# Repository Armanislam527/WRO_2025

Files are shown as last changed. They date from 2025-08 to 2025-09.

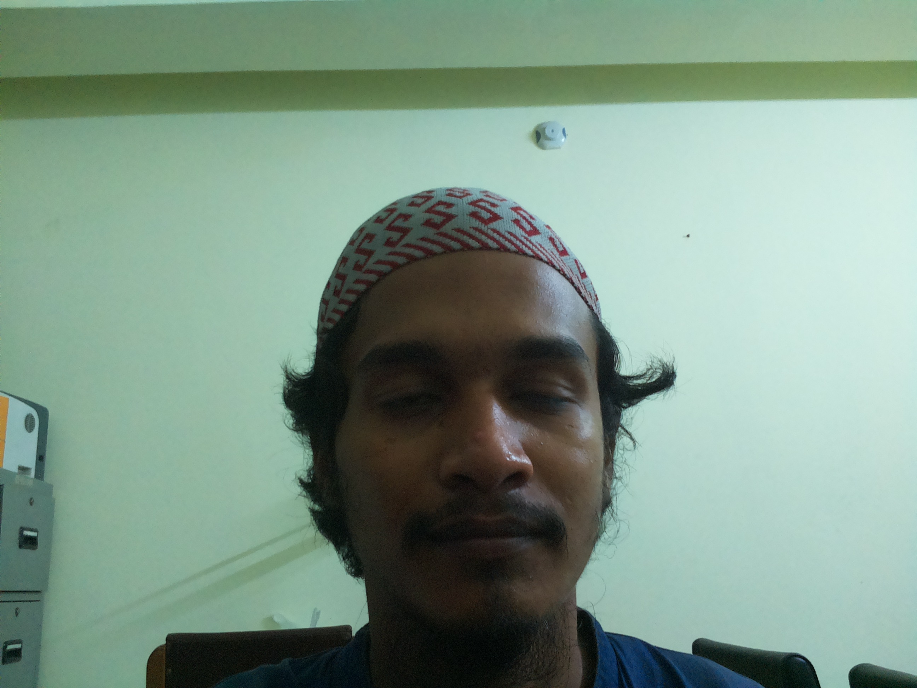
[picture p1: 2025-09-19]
test.jpg

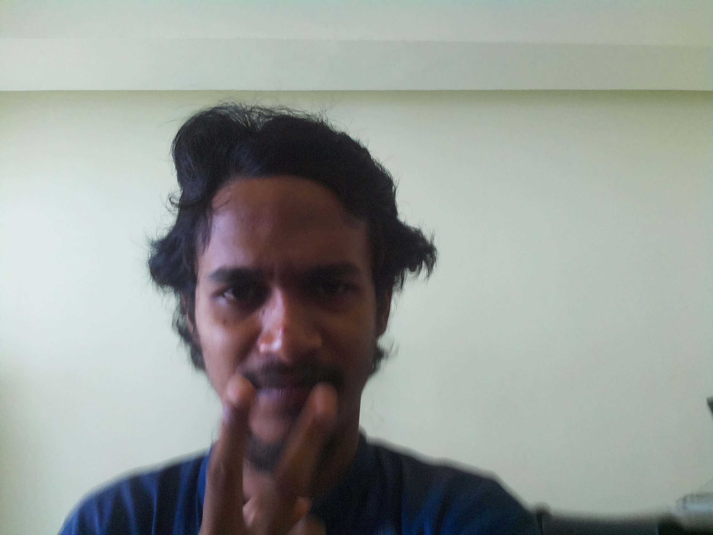
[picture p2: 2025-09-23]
Pictures/test.jpg

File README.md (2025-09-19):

# WRO 2025 Future Engineers: Self-Driving Car - Team void_error

<!-- ![void_error Team Logo or Action Shot](Pictures/team_in_action.jpg) *Consider adding a team logo or a dynamic action shot here* -->

**Team Members:**

-   **Arman** (Leader) - Lead Programmer, Chassis Designer [Arman](http://github.com/Armanislam527/WRO_2025/tree/main/Pictures/arman.jpeg)
-   **Sajid Hasan Rohit** -Member [Rohit](http://github.com/Armanislam527/WRO_2025/tree/main/Pictures/rohit.jpeg)
-   **Habibul Bashar Labib** - Member [Labib](http://github.com/Armanislam527/WRO_2025/tree/main/Pictures/labib.jpg)
-   **Basim Al Zabir Shammo** (Coach) - Guide and inspires the team to build the project [Shammo](http://github.com/Armanislam527/WRO_2025/tree/main/Pictures/shammo.jpg)

**Affiliation:** [Pabna University of Science and technology,Pabna,Bangladesh]

**Repository Status:**  

## 1. Project Philosophy & Introduction

Welcome to the engineering journey of Team void_error for the WRO 2025 Future Engineers category!

This repository serves as the living archive of our autonomous vehicle project, meticulously crafted for the Self-Driving Car challenges. Our endeavor transcends merely building a robot; it embodies our commitment to the WRO Guiding Principles, emphasizing learning, teamwork, creativity, and ethical competition.

We believe engineering is a symphony of iterative design, rigorous problem-solving, and seamless collaboration. This project reflects that belief. From the initial spark of an idea, through countless hours of design, coding, testing, debugging, and refining, every commit in this repository tells a story of our growth, our challenges overcome, and our relentless pursuit of excellence on the WRO track.

Our vehicle is not just a collection of electromechanical parts; it is the physical manifestation of algorithms, strategic thinking, and the fusion of open-source hardware and software. It is designed to perceive its environment, make intelligent decisions, and navigate the randomized complexities of the Open and Obstacle Challenges with precision and autonomy.

## 2. Vehicle Description & Key Features

### 2.1. Core Design Ethos

Our design philosophy centers on **robustness, modularity, and efficiency**. We aimed to create a platform that is not only competitive but also adaptable and easy to maintain. Key tenets include:

-   **Distributed Intelligence:** Leveraging both the computational strengths of the Raspberry Pi Zero 2W (for complex vision tasks) and the real-time control capabilities of the Arduino Nano (for sensor fusion and actuator control) to achieve optimal performance.
-   **Sensor Fusion:** Integrating data from multiple sensors (IMU, IR, Ultrasonics, Camera) to build a comprehensive understanding of the vehicle's state and its surroundings, leading to more informed and reliable decisions.
-   **Transparent Communication:** Implementing a clear, high-speed serial protocol between the Pi and Nano to ensure seamless coordination and data exchange.
-   **Iterative Development:** Our approach involved continuous testing, analysis of results, identification of bottlenecks, and targeted refinements. This process is documented through our commit history.

### 2.2. Mechanical Architecture

-   **Chassis:** A custom-designed, 3D-printed frame tailored for a **4-Wheel Drive (4WD) configuration with front-wheel steering**. This design provides superior traction and stability, crucial for the dynamic nature of the WRO tracks. The STL and GCODE files reside in the `RC Chassis/` directory, representing numerous iterations for optimal weight distribution and component integration.
-   **Propulsion:** **Rear-wheel drive** is implemented using high-torque DC motors, delivering the necessary power for acceleration and overcoming minor inclines or resistances on the track.
-   **Steering:** Precise directional control is achieved through a **front-wheel steering mechanism** actuated by a dedicated servo motor, enabling agile turns and accurate path following.
-   **Compliance:** The vehicle strictly adheres to WRO dimensional regulations (maximum 300mm length x 200mm width x 300mm height).
-   **Materials:** The primary structure utilizes **PLA filament** for 3D-printed components, balancing strength, printability, and weight. Standard RC components are integrated where appropriate for specific functionalities like motors and servos.

### 2.3. Electronic & Control Systems

The vehicle's nervous system is a carefully orchestrated interplay of controllers, sensors, and actuators.

-   **Dual-Controller Architecture:**
    -   **Primary Controller (Brain): Arduino Nano (`nano_brain/nano_brain.ino`)**
        -   **Responsibilities:** Acts as the real-time control hub. Manages low-level sensor interfacing (MPU6050 IMU, IR sensors, Ultrasonic sensors), executes core navigation algorithms (line following, turn detection using IMU integration, lap counting), directly controls actuators (motors via L298N H-Bridge, steering servo), and handles high-speed serial communication with the Pi.
        -   **Key Strengths:** Deterministic real-time performance, efficient handling of time-critical tasks, robust sensor data acquisition and preprocessing.
    -   **Secondary Controller (Vision/Strategy): Raspberry Pi Zero 2W (`coding_part/pi_main.py`)**
        -   **Responsibilities:** Serves as the high-level intelligence unit. Processes visual data from the onboard camera using computer vision techniques, implements complex decision-making logic (path planning, obstacle/sign interpretation), manages the overall mission state machine, and communicates strategic commands (desired speed, steering angle) to the Nano.
        -   **Key Strengths:** Powerful computational capabilities for image processing, ability to run complex algorithms, flexible software environment for rapid prototyping and strategy adjustments.
-   **Sensor Suite:**
    -   **MPU6050 IMU:** Critical for inertial navigation, specifically employed for highly accurate **gyroscopic turn detection** (by integrating the Z-axis rate) and reliable **lap counting**.
    -   **IR Reflectance Sensors (x4):** Strategically positioned to detect the contrast between the track surface and its boundaries, forming the backbone of the **line-following algorithm**.
    -   **Ultrasonic Distance Sensors (x2):** Provide range measurements to the front and rear, useful for obstacle detection (in Obstacle Challenge) and potentially for parking maneuvers.
    -   **USB Camera:** The primary sensor for environmental perception, feeding visual data to the Pi for advanced processing.
-   **Actuation:**
    -   **DC Motors (x2 - Rear Drive):** Controlled precisely via the L298N H-Bridge driver, enabling forward, backward, and variable speed movement.
    -   **Servo Motor (x1 - Front Steering):** Provides accurate angular control for steering, translating high-level directional commands into physical wheel movement.
-   **Communication Backbone:** A **high-speed serial link (configured at 500,000 baud)** ensures low-latency, reliable data transfer between the Pi and Nano, facilitating real-time coordination.
-   **Power Management:** A dedicated strategy involves a **lithium-ion battery pack**. Power is distributed via a **buck converter** to provide a stable 5V supply for the logic circuits (Nano, Pi, sensors) and direct, regulated power to the motor drivers for optimal performance.

### 2.4. Vehicle view

-   ## The vehicle view is below:
    -**<br>Front View [Front Vied](http://github.com/Armanislam527/WRO_2025/tree/main/Pictures/front.jpeg)**<br> -**Left View [Left View](http://github.com/Armanislam527/WRO_2025/tree/main/Pictures/lef.jpeg)**<br> -**Right View [Right View](http://github.com/Armanislam527/WRO_2025/tree/main/Pictures/right.jpeg)**<br> -**Rear View [Rear View](http://github.com/Armanislam527/WRO_2025/tree/main/Pictures/rear_view.jpeg)**<br> -**Top View [Top View](http://github.com/Armanislam527/WRO_2025/tree/main/Pictures/up.jpeg)**<br> -**Bottom View [Bottom View](http://github.com/Armanislam527/WRO_2025/tree/main/Pictures/down.jpeg)**<br>

## 3. Software Architecture & Modules

The software for our WRO 2025 vehicle is a distributed system split between the **Arduino Nano** and the **Raspberry Pi Zero 2W**, leveraging the strengths of each platform.

-   **Arduino Nano (`nano_brain/`):** This microcontroller acts as the real-time control core. Its responsibilities include:

    -   **Low-Latency I/O:** Reading sensors (IR, Ultrasonics, MPU6050) and controlling actuators (motors via L298N, servo) with precise timing.
    -   **Sensor Fusion & Preprocessing:** Performing initial processing on raw sensor data (e.g., reading MPU6050 registers, basic IR/US filtering).
    -   **Reliable Communication:** Managing the high-speed serial link with the Pi, packaging sensor data, and interpreting commands.
    -   **Fallback Logic:** Potentially executing basic reactive behaviors (like simple line following or emergency stops) if communication with the Pi is lost.
    -   **Code Language:** C++ (Arduino Sketch `.ino`).

-   **Raspberry Pi Zero 2W (`coding_part/`):** This single-board computer (SBC) handles high-level computation and strategy:
    -   **Computer Vision (CV):** Capturing images from the USB camera and processing them using libraries like OpenCV (`cv2`) to extract critical information such as lane position, traffic sign detection, and potentially parking lot identification.
    -   **Complex Decision Making:** Implementing the core navigation strategy, including line-following control algorithms (e.g., PID), interpreting sensor data (especially fused IMU data for turns/laps), managing the mission state machine (Start, Lap Driving, Sign Obeying, Parking Search, Parking Maneuver), and determining high-level commands (target speed, steering angle).
    -   **Path Planning:** Calculating the desired trajectory based on the perceived environment and challenge rules.
    -   **Communication Coordination:** Sending calculated commands (motor speeds, servo angles) to the Nano via the serial link.
    -   **Code Language:** Python 3.x.

Communication between the two is achieved via a **high-speed, binary serial protocol**. The Nano periodically sends sensor data packets to the Pi, and the Pi sends back actuator command packets. This decouples high-level cognition from real-time control, enhancing overall system responsiveness and robustness.

### 3.1. Arduino Nano (`nano_brain/nano_brain.ino`)

This section details the core logic running on the Arduino Nano, the vehicle's real-time processing unit.

-   **Initialization (`void setup()`):**

    1.  **Pin Configuration:** Initializes digital and PWM pins for motors (`MOTOR_IN1`, `MOTOR_IN2`, `MOTOR_PWM`), servo (`SERVO_PIN`), and digital inputs for sensors (`IR_PINS`, `START_BUTTON_PIN`).
    2.  **Peripheral Setup:**
        -   **I2C Bus:** Initializes the I2C bus (`Wire.begin()`) for communication with the MPU6050 IMU.
        -   **MPU6050:** Attempts to initialize the MPU6050 sensor. It writes to configuration registers (Power Management, Gyro/Accel config) and verifies communication by reading the `WHO_AM_I` register. Sends a status message (`NANO_READY_MPU_OK` or `NANO_READY_MPU_FAIL`) via serial.
        -   **Servo Attachment:** Attaches the steering servo to its designated pin using the `Servo` library.
    3.  **Serial Communication:** Begins serial communication at the predefined high baud rate (`SERIAL_BAUD`, e.g., 500000) to establish the link with the Pi.
    4.  **Timer Initialization:** Records the initial timestamp (`last_sensor_send_time`, `last_button_check_time`) for managing periodic tasks.

-   **Main Control Loop (`void loop()`):**

    1.  **Periodic Tasks:**
        -   **Button Check:** Periodically polls the start button pin with software debouncing to detect the official start signal from the judge.
        -   **Sensor Reading:** Calls functions to read data from all connected sensors (IR array, Ultrasonic sensors, MPU6050). This involves reading digital pins, sending trigger pulses, measuring echo durations, and performing I2C transactions with the IMU.
        -   **Data Packaging:** Combines the acquired sensor data into a structured format (e.g., a `SensorData` struct) for efficient transmission.
    2.  **Communication Handling:**
        -   **Sensor Transmission:** At a fixed interval (`SENSOR_SEND_INTERVAL_MS`), serializes the packaged `SensorData` struct and sends it to the Pi using a defined binary packet structure (e.g., `0xAA` header, data bytes, `0x55` footer).
        -   **Command Reception:** Listens for incoming serial data from the Pi. Parses command packets (e.g., `CMD:<speed>,<angle>\n`, `ENABLE_PI_CONTROL\n`) and updates internal target variables (`target_motor_speed`, `target_servo_angle`) or state flags (`pi_control_override`).
    3.  **Actuator Control:**
        -   **Motor Control:** Updates the motor driver outputs (`digitalWrite` to IN pins, `analogWrite` to EN pin) based on the current `target_motor_speed`.
        -   **Servo Control:** Updates the servo position (`steering_servo.write()`) based on the current `target_servo_angle`.
    4.  **State Management:**
        -   Waits in a loop until the start button signal is received and processed.
        -   Responds to the `pi_control_override` flag. If true, it executes commands received from the Pi. If false (e.g., fallback mode), it might execute a basic local control routine.

-   **Key Supporting Functions:**
    -   `bool initialize_mpu6050()`: Handles the specific initialization sequence for the MPU6050.
    -   `void read_ir_sensors()`, `int16_t read_ultrasonic(...)`, `void read_mpu6050_data()`: Dedicated functions for reading individual sensor types.
    -   `void process_serial_command()`: Parses incoming serial data from the Pi.
    -   `void update_motors()`, `void update_servo()`: Wrapper functions to apply the calculated target values to the physical actuators.

### 3.2. Raspberry Pi Zero 2W (`coding_part/pi_main.py`)

This section outlines the high-level Python script running on the Raspberry Pi Zero 2W, responsible for vision, strategy, and commanding the Nano.

-   **Initialization (`def main()` and setup code):**

    1.  **Library Imports:** Imports necessary Python libraries (`serial`, `cv2`, `numpy`, `time`, `threading`, etc.).
    2.  **Configuration Loading:** Reads configuration parameters (e.g., serial port `SERIAL_PORT`, baud rate `BAUD_RATE`, camera resolution `FRAME_WIDTH` x `FRAME_HEIGHT`, HSV color ranges for line/sign detection, control gains like `STEERING_P_GAIN`).
    3.  **Serial Connection:** Establishes a serial connection to the Arduino Nano using `pyserial` with the matching port and high baud rate.
    4.  **Camera Setup:** Initializes the USB camera using `cv2.VideoCapture`, setting properties like resolution and potentially buffer size for optimal performance.
    5.  **State Variable Initialization:** Resets run-specific variables (e.g., `state = STATE_WAITING_FOR_START`, `lap_count = 0`, `turn_count = 0`, sensor data buffers).
    6.  **Threading (Optional but Recommended):** Starts a separate thread dedicated to continuously reading sensor data packets from the serial port. This prevents the main control loop from blocking on serial reads. This thread parses incoming packets and updates shared data variables (e.g., `imu_data_raw`, `ir_sensor_states`) in a thread-safe manner (e.g., using `threading.Lock`).

-   **Main Execution Loop (`while not stop_event.is_set():` within `main()`):**

    1.  **Start Signal Handling:** Checks for the "START" signal received from the Nano (either via a specific flag set by the serial reader thread or by parsing a startup message). Upon receiving it, transitions the internal state machine to `STATE_DRIVING_LAPS`.
    2.  **Sensor Data Access:** Retrieves the latest sensor data shared by the serial reader thread (e.g., IMU gyro Z for turn counting, IR states for line following adjustments).
    3.  **Camera Processing (`process_camera_frame()`):**
        -   **Image Capture:** Grabs a frame from the camera (`cap.read()`).
        -   **Preprocessing:** Applies necessary corrections (e.g., resizing, color space conversion like BGR to HSV).
        -   **Feature Detection:**
            -   **Lane Following:** Analyzes the frame (e.g., ROI near the bottom) using techniques like color thresholding (white/black) and edge detection to find the track boundaries. Calculates a lateral error (distance from vehicle centerline to track center).
            -   **Traffic Sign Detection:** Uses color filtering (red/green HSV ranges) and shape analysis (contour detection) to identify and locate traffic signs relative to the vehicle.
            -   **Parking Lot Detection (Obstacle Challenge):** Looks for specific visual markers (e.g., magenta boundaries) to identify the parking lot entrance.
        -   **Output:** Returns the calculated lane error, detected sign information (type, position), and parking lot information (if detected).
    4.  **State Machine Logic (`calculate_control_commands()`):**
        -   Based on the current `state` (e.g., `STATE_DRIVING_LAPS`, `STATE_OBEYING_SIGN`, `STATE_PARKING_SEARCH`, `STATE_PARKING_MANEUVER`), it:
            -   **Integrates Sensor Data:** Uses IMU gyro Z data to count turns and laps.
            -   **Applies Control Laws:** Implements algorithms (e.g., Proportional-Derivative (PD) control) based on the lane error from vision to calculate the desired steering angle. Adjusts base speed based on steering effort or state requirements.
            -   **Manages Missions:** Handles logic for obeying traffic signs (modifying path based on sign color/side) and executing the parking sequence (searching for lot, performing maneuvers).
            -   **State Transitions:** Automatically transitions between states (e.g., from `DRIVING_LAPS` to `PARKING_SEARCH` after 3 laps, from `OBEYING_SIGN` back to `DRIVING_LAPS`).
    5.  **Command Generation:** Based on the outputs of the state machine and control logic, calculates the final `motor_speed` (integer, -255 to 255) and `servo_angle` (integer, 0 to 180).
    6.  **Serial Communication (`send_command_to_nano()`):**
        -   Formats the calculated commands into the agreed-upon protocol packet (e.g., `CMD:<motor_speed>,<servo_angle>\n`).
        -   Sends the packet to the Nano via the serial port.
    7.  **Loop Timing:** Controls the loop rate (e.g., using `time.sleep()`) to ensure stable processing and communication without overwhelming the system.

-   **Key Supporting Functions:**
    -   `def process_camera_frame(frame)`: Encapsulates the computer vision pipeline.
    -   `def update_lap_count(gyro_z_rate)`: Handles the integration of IMU data for accurate lap and turn counting.
    -   `def calculate_control_commands(...)`: Contains the core decision-making and control algorithm logic.
    -   `def send_command_to_nano(command_str)`: Handles formatting and transmitting commands via serial.
    -   `def serial_reader_thread()`: (If used) The function run by the background thread for asynchronous serial data reception.

## 4. Building, Flashing, and Running the Vehicle

This section provides a step-by-step guide to reproduce the hardware assembly and software setup of our WRO 2025 vehicle. Following these instructions should allow another competent team to build and run a functionally equivalent vehicle based on our design and code.

### 4.1. Prerequisites

Before beginning the build, ensure you have the following components, tools, and software environments ready.

-   **Hardware Components:**
    -   **Electromechanical Parts:**
        -   1x Arduino Nano (ATmega328P)
        -   1x Raspberry Pi Zero 2W
        -   1x MicroSD Card (8GB or larger, Class 10 recommended) pre-flashed with Raspberry Pi OS Bullseye or Bookworm Lite
        -   1x L298N Dual H-Bridge Motor Driver Module
        -   2x DC Motors with Gearbox (e.g., 6V, 200:1 reduction ratio)
        -   1x Standard Servo Motor (e.g., SG90 or MG90S)
        -   4x Digital Infrared (IR) Reflectance Sensors (e.g., TCRT5000 or equivalent)
        -   2x Ultrasonic Distance Sensors (e.g., HC-SR04)
        -   1x MPU6050 6-Axis Gyro/Accelerometer Module
        -   1x Wide-Angle USB Camera Module (e.g., compatible with Pi Zero)
        -   1x 4WD RC Chassis Kit (or custom 3D printed frame - see `RC Chassis/`)
        -   4x Wheels (compatible with motors/axles)
        -   1x Steering Linkage (tie rods, steering knuckle - custom or from RC kit)
        -   Jumper Wires (Male-to-Male, Male-to-Female, Female-to-Female)
        -   1x Mini Breadboard
        -   1x 18650 Lithium-Ion Battery Pack (e.g., 4S, ~14.8V, 7800mAh) with holder
        -   1x 5V Buck Converter Module (e.g., MP1584 or LM2596)
        -   1x Push Button (Momentary, Normally Open)
        -   1x 10kΩ Resistor (for button pull-up)
        -   1x Power Switch
        -   Fasteners (screws, nuts, zip ties) for mounting components
    -   **Tools:**
        -   Phillips Head Screwdriver
        -   Soldering Iron and Solder (for secure electrical connections)
        -   Wire Strippers/Cutters
        -   Allen Keys (if required for 3D printed parts or RC kit)
        -   3D Printer (if using custom `RC Chassis/` models) or access to laser cutting/CNC (if applicable)
        -   Calipers (for precise measurements during assembly)
-   **Software Environment:**
    -   **On a Development Computer:**
        -   Arduino IDE (version 1.8.19 or later, or Arduino CLI) for flashing the Nano.
        -   Git client for cloning this repository.
        -   (Optional but Recommended) Visual Studio Code or similar IDE for editing Python code.
    -   **On the Raspberry Pi Zero 2W:**
        -   Raspberry Pi OS (Bullseye Lite or Bookworm Lite recommended for performance/resource usage).
        -   Python 3.x (usually pre-installed).
        -   Required Python Libraries:
            -   `opencv-python` (for camera and computer vision)
            -   `numpy` (numerical computations)
            -   `pyserial` (for serial communication with Nano)
            -   `smbus2` or `smbus` (for I2C communication with MPU6050, if needed by alternative libraries)
            -   `RPi.GPIO` (usually pre-installed, for GPIO control if needed directly on Pi)
        -   Internet access on the Pi (via USB Ethernet gadget, WiFi, or Ethernet) for initial software installation.

### 4.2. Hardware Assembly

Follow these steps to assemble the physical vehicle. Reference the 3D models in `RC Chassis/` and the pin diagrams in `pin_diagram/` for precise component placement and connections.

1.  **Prepare the Chassis:**
    -   If using the custom 3D printed design, print the required parts from the STL files in `RC Chassis/` using appropriate settings (e.g., 0.2mm layer height, 20% infill). Ensure print quality is good, especially for parts requiring precise fit (motor mounts, servo mounts).
    -   If using an RC kit, follow the kit's instructions for the base frame assembly.
    -   Identify mounting points for the Arduino Nano, Raspberry Pi, L298N driver, battery pack, and sensors.
2.  **Mount Electronic Components:**
    -   **Arduino Nano & Breadboard:** Secure the Arduino Nano and mini breadboard to the chassis using standoffs or adhesive pads. Ensure it's firmly attached and vibration-resistant.
    -   **Raspberry Pi Zero 2W:** Mount the Pi in a safe, accessible location, ideally with a protective case. Ensure the USB camera can be mounted with an unobstructed view ahead.
    -   **L298N Driver:** Mount the L298N driver, ensuring adequate ventilation if it gets hot. Secure it firmly.
    -   **Sensors:**
        -   **IR Sensors (x4):** Mount the IR sensors beneath the front of the chassis. Angle them slightly inwards to detect the track edges. The front-left (FL) and front-right (FR) sensors should point towards the immediate track boundary. The right-45 (R45) and left-45 (L45) sensors should be angled ~45 degrees outwards to provide additional lateral awareness or assist with turn detection/sign reading. Ensure they are at a consistent, low height above the track surface.
        -   **Ultrasonic Sensors (x2):** Mount one US sensor on the front bumper and one on the rear bumper. Ensure the transducers are perpendicular to the front/rear surfaces for accurate distance measurement.
        -   **MPU6050 IMU:** Mount the IMU module in a central, stable location on the chassis, away from high-current cables (like those to the motors) to minimize electromagnetic interference. Orient it consistently (e.g., chip side up, specific axis forward) and note the orientation for potential calibration.
        -   **Servo Motor:** Mount the steering servo securely in the designated position (usually part of the 3D printed steering assembly or RC kit). Connect the steering linkage (tie rods) from the servo arm to the steering knuckle/axle.
    -   **Motors:** Attach the DC motors to the motor mounts on the chassis. Connect the wheels to the motor shafts/axles. Ensure the rear wheels are the drive wheels.
    -   **Camera:** Mount the USB camera at the front, elevated and tilted slightly downwards to capture the track ahead. The exact height and angle might require fine-tuning during calibration.
3.  **Complete Electrical Connections:**
    -   **Crucial:** Double-check _every_ connection against the wiring diagrams provided in `pin_diagram/data_connection.csv` and `pin_diagram/power_source.csv`. Incorrect wiring can damage components.
    -   **Power Distribution:**
        -   Connect the positive terminal of the 18650 battery pack to the `VCC` input of the L298N module.
        -   Connect the negative terminal of the battery pack to the `GND` input of the L298N and to the common ground rail of your main power distribution system (e.g., breadboard GND rail).
        -   Connect the `5V` output of the Buck Converter to the `+5V` power rail (e.g., breadboard `+` rail).
        -   Connect the `GND` output of the Buck Converter to the common ground rail (e.g., breadboard `-` rail).
        -   Power the Arduino Nano, Raspberry Pi, Sensors, and Servo Logic from the `+5V` and `GND` rails.
    -   **Nano to Components:**
        -   Connect Nano pins to IR sensor digital outputs, US sensor trigger/echo pins, servo signal pin, L298N control pins (ENA, IN1, IN2, IN3, IN4, ENB if using 2 motors), MPU6050 SDA/SCL pins, and the start button pin, according to `nano_brain/nano_brain.ino` and `pin_diagram/data_connection.csv`.
        -   Ensure correct I2C pull-up resistors are used or present on the MPU6050 module.
    -   **Pi to Components:**
        -   Connect the Pi's camera module to the dedicated CSI port.
        -   Connect the Pi's USB OTG port to the Arduino Nano's USB port (for power and serial communication). _Or_, if using separate power and UART serial:
            -   Connect Pi's UART TX (GPIO 14) to Nano's RX (D0) via a logic level shifter if needed (though often 3.3V->5V works for RX).
            -   Connect Pi's UART RX (GPIO 15) to Nano's TX (D1) via a logic level shifter (5V->3.3V is _required_ here).
            -   Connect Pi's GND to Nano's GND.
    -   **L298N to Motors:**
        -   Connect motor power (from battery pack `VCC` and `GND`) to the L298N motor supply terminals.
        -   Connect the two DC motor wires to the L298N output terminals (OUT1/OUT2 for Motor A, OUT3/OUT4 for Motor B).
        -   Connect the L298N logic control pins (ENA, IN1, IN2, IN3, IN4, ENB) to the corresponding Arduino Nano pins.
    -   **Start Button & Switch:**
        -   Wire the push button between the designated Nano input pin (e.g., A3) and GND. Use the internal pull-up resistor configured in the Nano code (`pinMode(START_BUTTON_PIN, INPUT_PULLUP);`) or add an external 10kΩ pull-up resistor between the pin and `+5V`.
        -   Wire the main power switch in series with the positive lead from the battery pack.
    -   **Pin Diagram:**
        -   The pin diagram is below:
        -   [Circuit](http://github.com/Armanislam527/WRO_2025/tree/main/Pictures/circuit_image.svg)

-   4.  **Final Checks:**
    -   Visually inspect all connections for solder bridges, loose wires, or incorrect plugs.
    -   Ensure no components are shorted or obstructing moving parts.
    -   Verify the orientation of polarized components (diodes, electrolytic capacitors, motor connectors).
    -   Secure all loose wires with zip ties to prevent them from getting caught in wheels or moving parts.

### 4.3. Software Installation & Flashing

This step involves uploading the control code to the Arduino Nano and setting up the environment and code on the Raspberry Pi Zero 2W.

1.  **Clone this Repository:**
    -   On your development computer (or directly on the Pi if preferred and internet is available):
    ```bash
    git clone https://github.com/armanislam527/WRO_2025.git
    cd WRO_2025
    ```
2.  **Flash Arduino Nano (`nano_brain/nano_brain.ino`):**
    -   Connect the Arduino Nano to your development computer via a USB cable.
    -   Open the Arduino IDE.
    -   Go to `File -> Open` and navigate to `WRO_2025/nano_brain/nano_brain.ino`.
    -   Install required libraries if prompted (e.g., `Servo`, `Wire`). You can usually do this via `Tools -> Manage Libraries...`.
    -   In the Arduino IDE, go to `Tools -> Board` and select `Arduino Nano`.
    -   Go to `Tools -> Processor` and select `ATmega328P (Old Bootloader)` (or the correct variant for your specific Nano).
    -   Go to `Tools -> Port` and select the port corresponding to your connected Nano (e.g., `/dev/ttyUSB0` or `COM3`).
    -   Click the `Upload` button (Right Arrow icon). Wait for the compilation and upload process to complete successfully. The Nano's LED should blink during upload.
3.  **Setup Raspberry Pi Software (`coding_part/pi_main.py`):**
    -   Insert the flashed MicroSD card into the Raspberry Pi Zero 2W.
    -   Connect the Pi to a monitor, keyboard, and power. Boot it up and connect to the internet.
    -   Open a terminal.
    -   Update the package list:
        ```bash
        sudo apt update
        ```
    -   Install the required Python libraries:
        ```bash
        sudo apt install python3-opencv python3-numpy python3-serial python3-smbus -y
        # Note: python3-rpi.gpio is usually pre-installed. Install if needed: sudo apt install python3-rpi.gpio
        ```
    -   (Optional but Recommended) Enable the camera interface if not already done:
        ```bash
        sudo raspi-config
        ```
        Navigate to `Interface Options` -> `Camera` and enable it. Reboot if prompted.
    -   Transfer the `coding_part/` directory (containing `pi_main.py` and potentially other helper scripts) from this repository to the Pi. You can use `scp`, a USB drive, or clone the repo directly on the Pi (as shown in step 1).
        -   Example using `scp` from your development computer (replace `pi@your_pi_ip` with the actual IP address of your Pi):
        ```bash
        scp -r WRO_2025/coding_part/* pi@your_pi_ip:/home/pi/
        ```
    -   Make the main script executable (optional, but good practice if it has a shebang):
        ```bash
        chmod +x /home/pi/pi_main.py # Adjust path if copied elsewhere
        ```

### 4.4. Running the Vehicle

Once hardware is assembled and software is installed/flashed, follow these steps to operate the vehicle.

1.  **Power On:**
    -   Ensure the vehicle is placed in a safe, clear area.
    -   Flip the main power switch to the ON position.
    -   The Arduino Nano should initialize. It might send a status message like `NANO_READY_MPU_OK` or `NANO_READY_MPU_FAIL` via serial (you won't see this unless you connect a serial monitor, but the Pi will listen for it).
2.  **Establish Communication (Pi - Nano):**
    -   Power on the Raspberry Pi Zero 2W.
    -   The Pi will boot up. Ensure it recognizes the Arduino Nano via the configured serial connection (USB serial or UART pins). The `pi_main.py` script is designed to handle this.
3.  **Prepare for Start:**
    -   Position the vehicle at the starting zone on the WRO track, oriented correctly according to WRO rules (front axle closer to the first corner in the driving direction).
4.  **Initiate Run:**
    -   On the Pi (via SSH or directly connected screen/keyboard), navigate to the directory containing `pi_main.py`.
    -   Run the Python script:
        ```bash
        python3 /home/pi/pi_main.py # Adjust path if necessary
        ```
    -   The script will initialize the camera and serial connection. It should wait for the start signal.
    -   Press the designated start button (connected to the Nano) once. The Nano acknowledges the button press and sends a `START` signal via serial.
    -   The Pi receives the `START` signal, and the main control loop begins. The vehicle should start moving autonomously according to its programmed logic for the Open Challenge.
5.  **Monitoring & Operation:**
    -   The vehicle will attempt to drive 3 laps and stop in the starting section.
    -   Observe its behavior. Debug logs (printed by `pi_main.py`) can provide insights into sensor readings and decisions.
    -   For the Obstacle Challenge, the strategy implemented in `pi_main.py` would need to be activated/selected (potentially via command-line arguments or internal state machine logic once the Pi takes over from the Nano's basic auto mode).
6.  **Shutting Down:**
    -   To stop the run prematurely (e.g., for adjustments), you can press `Ctrl+C` in the Pi's terminal running the script.
    -   To power off the vehicle, flip the main power switch to the OFF position _after_ ensuring the Pi has shut down properly (use `sudo shutdown -h now` on the Pi if accessing it directly).

## 5. Repository Structure

This repository is organized to provide clear separation and easy access to the different components of our WRO 2025 vehicle project. Understanding this structure is key to navigating the code and documentation.<br>
WRO_2025/<br>
├── LICENSE # Repository license (e.g., MIT, GPL)<br>
├── README.md # This comprehensive documentation file.<br>

├── .gitignore # (Recommended) Specifies intentionally untracked files to ignore (e.g., \*\*<br>.pyc, pycache/).<br>

├── rulebook/ # Official WRO 2025 rule documents for reference.<br>
│ ├── WRO-2025-Future-Engineers-Self-Driving-Cars-General-Rules.pdf<br>
│ └── ... (other rule documents)<br>
├── nano_brain/ # Core Arduino Nano code for real-time control.<br>
│ └── nano_brain.ino # Main Arduino sketch. Contains sensor reading, actuator control, serial communication.<br>
├── coding_part/ # Raspberry Pi Zero 2W code and related scripts.<br>
│ ├── pi_main.py # Primary Python script for high-level control, vision, strategy.<br>
│ ├── rpi.py # (If this is an older/duplicate version, consider deleting or clarify its purpose)<br>
│ ├── color_detection.py # (If used) Dedicated module for specific CV tasks like color filtering.<br>
│ ├── arnano.cpp # (Appears to be a C++ version or duplicate, clarify or remove if obsolete)<br>
│ ├── arnano/ # (Contains arnano.ino, likely obsolete/duplicate, clarify/remove)<br>
│ │ └── arnano.ino<br>
│ ├── deepseek/ # (Appears to be experimental/older code versions, clarify/remove)<br>
│ │ ├── nano_code/ # (Contains nano_code.ino, likely obsolete/duplicate)<br>
│ │ │ └── nano_code.ino<br>
│ │ ├── pi_main.py # (Likely an older/duplicate version)<br>
│ │ └── ...<br>
│ ├── perplexity/ # (Appears to be experimental/older code versions, clarify/remove)<br>
│ │ ├── nano_code/ # (Contains nano_code.ino, likely obsolete/duplicate)<br>
│ │ │ └── nano_code.ino<br>
│ │ └── pi_main.py # (Likely an older/duplicate version)<br>
│ ├── qween/ # (Appears to be experimental/older code versions, clarify/remove)<br>
│ │ └── qween_pi_main.py # (Likely an older/duplicate version)
<br>│ └── wro-car # (Unclear purpose, clarify. If a service script, consider moving to a 'scripts/' dir)
<br>├── pin_diagram/ # Visual and data files detailing electronic connections.
<br>│ ├── nano_pin_diagram.webp # Visual representation of Nano wiring.
<br>│ ├── pi_zero_pinou.png # Visual representation of Pi wiring (note typo in filename).
<br>│ ├── data_connection.csv # Tabular data mapping signal names to specific pins.
<br>│ ├── visual_diagram.jpg # (Optional) Another visual aid if needed.
<br>│ └── power_source.csv # Details on power distribution (battery, regulators, connections).
<br>├── Pictures/ # Images crucial for documentation and team identity.

<!-- <br>│ ├── team_photo.jpg # Mandatory team photo as per WRO rules. -->

<br>│ ├── arman.jpeg # Individual team member photos.
<br>│ ├── labib.jpg
<br>│ ├── rohit.jpeg
<br>│ ├── shammo.jpg

<!-- <br>│ ├── team_in_action.jpg # (Recommended) Action shot of the team/vehicle. -->
<!-- <br>│ ├── vehicle_front_view.jpg # (Recommended) Clear photo of the front. -->
<!-- <br>│ ├── vehicle_rear_view.jpg # (Recommended) Clear photo of the rear. -->
<!-- <br>│ ├── vehicle_side_view.jpg # (Recommended) Clear photo of the side. -->
<!-- <br>│ ├── vehicle_top_view.jpg # (Recommended) Clear photo from above. -->
<!-- <br>│ ├── vehicle_bottom_view.jpg # (Recommended) Clear photo from below. -->
<!-- <br>│ ├── detail_steering.jpg # (Recommended) Close-up of steering mechanism. -->
<!-- <br>│ ├── detail_sensor_mount.jpg # (Recommended) Close-up of sensor mounting. -->

<br>│ └── testing.jpg # (Existing) Photo from development/testing.
<br>├── RC Chassis/ # 3D models and prints for the custom chassis and components.
<br>│ ├── frame.stl # Main chassis frame STL file.
<br>│ ├── frame.gcode # GCODE for 3D printing the frame.
<br>│ ├── front_wheeler.stl # STL for front wheel assembly (if custom).
<br>│ ├── Control arm.stl # STL for suspension/control arm (if custom).
<br>│ ├── Servo mount.stl # STL for the steering servo mount.
<br>│ ├── Motor mount A.stl # STL for one type of motor mount.
<br>│ ├── Motor mount B.stl # STL for another type of motor mount (if needed).
<br>│ ├── Rim.stl / Rim no support needed.stl # STL for wheel rims.
<br>│ ├── Tire.stl # STL for tire tread (if custom/printed).
<br>│ ├── Hub.stl # STL for wheel hub.
<br>│ ├── ... (other .stl/.gcode files for specific chassis parts)
<br>│ └── CURA_OUTPUT/ # (Optional) Folder containing sliced GCODE files if generated by Cura.
<br>├── scripts/ # (Optional but Recommended) Utility scripts for setup, deployment, etc.
<br>│ └── setup_pi.sh # (Example) Script to automate Pi software installation.
<br>└── docs/ # (Optional) Additional detailed documentation files (e.g., design notes, meeting logs - though main doc is README.md).
<br>└── (future detailed design docs could go here)

**Note on Code Organization:** The `coding_part/` directory currently contains several files and subdirectories that appear to be duplicates, older versions, or experimental branches (e.g., `deepseek/`, `perplexity/`, `qween/`, multiple `nano_code/` folders, `arnano.*`). For clarity and adherence to WRO's expectation of a clean, understandable repository, it is highly recommended to:

1.  **Review and Clean:** Assess the purpose of each file/folder within `coding_part/`.
2.  **Retain Essentials:** Keep only the actively used and final versions (e.g., `pi_main.py`).
3.  **Delete Obsolete:** Remove clearly outdated or duplicate files/folders.
4.  **Document if Kept:** If some experimental branches are kept for historical context, add a brief note in the `README.md` explaining their presence.

A clean repository structure significantly enhances the "GitHub Utilization" score by demonstrating organization and clarity.

### 6. Development Process & Commit History

This repository is a testament to our team's iterative development approach and commitment to the WRO Guiding Principles. Our process emphasized learning, experimentation, problem-solving, and meticulous documentation throughout the build season.

-   **Philosophy:** We embraced a cycle of **Design -> Implement -> Test -> Analyze -> Refine**. Ideas were rapidly prototyped, tested on the physical vehicle or in simulation, results were analyzed, and the design/code was refined based on findings. This approach is clearly visible in our commit history.
-   **Collaboration:** Team members collaborated closely, dividing tasks based on expertise (e.g., mechanical design, electronics, Arduino programming, Pi programming, computer vision). Regular discussions ensured alignment and knowledge sharing.
-   **Version Control Usage:** We utilized Git and GitHub extensively not just for backup, but as a core part of our workflow.
    -   **Regular Commits:** Throughout the development period, we made frequent, meaningful commits. Each commit message concisely describes the changes made (e.g., "Fix IMU calibration drift in turn detection", "Add initial camera undistortion parameters", "Refactor sensor data struct for clarity").
    -   **Milestone Tracking:** Key milestones and significant breakthroughs were marked by specific commits or tags (e.g., "Initial Nano-Pi serial communication established", "Working line-following prototype v1", "Integrated IMU-based lap counting").
    -   **Issue Resolution:** When encountering bugs or unexpected behavior (e.g., serial communication glitches, camera lag, sensor noise), the investigation, debugging process, and eventual fix were documented through a series of descriptive commits.
-   **WRO Rule Compliance:** Our commit history demonstrably fulfills the WRO requirements:
    -   **Timeliness:** Commits were made progressively throughout the season, well before competition deadlines.
    -   **Progression:** The commit history clearly shows the evolution of the project from initial concept sketches and basic hardware setup to the final, polished system. Early commits focus on foundational elements (basic sensor reading, motor control), while later commits refine complex algorithms (IMU integration, computer vision tuning, strategy state machine).
    -   **Ownership:** All code and design work reflected in the commits were performed by the team members, adhering to the rule against plagiarism (Rule 3.3, 3.7).
-   **Evidence of Effort:** The commit log provides concrete evidence of the substantial effort invested, including:
    -   Numerous iterations on sensor fusion and calibration routines.
    -   Continuous tuning of control loops (PID gains) for smoother driving.
    -   Refactoring and optimization of code for performance and readability.
    -   Integration challenges overcome (e.g., synchronizing Pi-Nano communication, handling multi-threading on the Pi).
    -   Adaptations based on real-world testing feedback.

By maintaining this detailed and progressive commit history, we ensure transparency, facilitate future debugging or enhancements, and most importantly, meet the "Exceeds expectations" criteria for **GitHub Utilization** (clear progression, problem-solving documentation) and contribute positively to the overall **Judge Impression** (demonstrates deep understanding, effort, and professionalism).

## 7. Performance Videos

Demonstration videos showcasing the vehicle's capabilities in action.

-   **Free Round Qualification Run (Successful 3 Laps):** [

    -   Link:Will be uploaded soon In Sha Allah
    -   Description: Shows the vehicle autonomously completing the required 3 laps in the Open Challenge configuration.

-   **Obstacle Round Attempt (Traffic Signs & Parking Search):** 
    -   Link:Will be uploaded soon In Sha Allah
    -   Description: Demonstrates the vehicle's attempt at the Obstacle Challenge, including detecting traffic signs and searching for the parking lot (even if parking execution wasn't fully successful).

## 8. Known Issues & Future Work

This section outlines current limitations observed during development and testing, as well as potential areas for future improvement.

-   **Known Issues:**
    -   **Camera Latency:** Under certain lighting conditions or with high computational load on the Pi, a slight delay in camera processing was observed, which could affect high-speed maneuvering precision.
    -   **Ultrasonic Sensor Noise:** Occasional erroneous readings from the ultrasonic sensors were noted, likely due to reflections or interference. Software filtering helped mitigate this but didn't eliminate it entirely.
    -   **Serial Communication Robustness:** While generally reliable, occasional data corruption was observed during intense motor activity, suggesting potential for EMI or buffer overflow issues under stress. Implementing a more robust checksum protocol could improve resilience.
-   **Future Work/Improvements:**
    -   **Advanced Path Planning:** Implement more sophisticated path planning algorithms (e.g., A\*\*<br>, potential fields) for dynamic obstacle avoidance and optimized lap times.
    -   **Enhanced Parking Algorithm:** Develop a more robust and adaptive parallel parking sequence using refined sensor fusion (camera + IMU + US) for higher success rates.
    -   **Modular Software Architecture:** Refactor the Pi code into more modular components (e.g., separate modules for vision, control, state machine) to improve maintainability and reusability.
    -   **Power Optimization:** Investigate further power optimization techniques for both Pi and Nano to extend potential runtime, especially if battery life becomes a limiting factor in longer runs or development sessions.

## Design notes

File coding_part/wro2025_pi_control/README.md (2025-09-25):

# WRO 2025 Self-Driving Car - Raspberry Pi Control

This repository contains the Bash-based control software for the Raspberry Pi 0 2W,
designed to interface with an Arduino Nano for the WRO 2025 Future Engineers Self-Driving Cars competition.

## Structure

-   `src/bash/`: Main Bash scripts (orchestrator, hardware interface, etc.).
-   `src/python/`: Python helpers (vision, sensor fusion).
-   `data/shared_state.json`: Current mission state.
-   `data/sensor_data.json`: Latest sensor readings from the Nano.
-   `data/nav_commands.json`: Commands from navigation to hardware interface.
-   `config/main_config.conf`: Main configuration file.

## Setup

1. Ensure dependencies are installed (jq, python3, opencv-python, numpy, pyserial).
2. Create necessary directories and files.
3. Upload the corresponding Arduino Nano firmware.

## Running

Use the main orchestrator script.

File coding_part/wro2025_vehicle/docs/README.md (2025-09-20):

# WRO 2025 Future Engineers: Self-Driving Car - Pi-Side Controller Software

This document provides a detailed description of the C++ software architecture and implementation for the Raspberry Pi Zero 2W component of our WRO 2025 Future Engineers Self-Driving Car entry, Team void_error. This software acts as the high-level intelligence unit, processing sensor data, making strategic decisions, and controlling the vehicle's actions.

## 1. Introduction & Philosophy

The Pi-side software is designed around a modular, event-driven architecture to handle the complex tasks of perception, navigation, and control required for the WRO 2025 challenge. It communicates with the Arduino Nano (handling real-time I/O and motor control) via a high-speed serial link. The code is structured to be maintainable, efficient, and to clearly separate concerns (e.g., vision, communication, navigation, control).

Our development process followed an iterative cycle: `Design -> Implement -> Test -> Analyze -> Refine`. This is reflected in the commit history and the evolution of the modules.

## 2. Core Components & Modules

The software is organized into several directories within the `src/` folder, each encapsulating a specific aspect of the vehicle's functionality.

### 2.1. Main Application (`src/main.cpp`)

This is the entry point of the application. It orchestrates the initialization of all subsystems, manages the main execution loop, and handles the overall mission state machine. It initializes and connects the `SerialHandler`, `CameraInterface`, `ImageProcessor`, `LapCounter`, `PathPlanner`, and `VehicleController`. The main loop continuously retrieves sensor and vision data, updates the `MissionState`, and dispatches control flow to specific handlers based on the current phase (e.g., `PRE_START`, `DRIVING_LAPS`, `STOPPING_AT_START`, `PARKING`).

### 2.2. Configuration (`src/config/`)

-   **`vehicle_config.h` / `vehicle_config.cpp`**: Centralizes configurable parameters such as serial port names, baud rates, camera settings, vehicle physical dimensions, and thresholds used across different modules. This makes tuning and adapting the software easier without modifying core logic.

### 2.3. Communication (`src/communication/`)

-   **`serial_handler.h` / `serial_handler.cpp`**: Manages the serial communication link with the Arduino Nano. It handles opening/closing the serial port, running a dedicated background thread for receiving data packets, parsing the binary protocol (start byte, command, length, data, checksum), and providing thread-safe access to the latest `SensorData`. It also includes methods to send commands to the Nano (motor speed, servo angle, heartbeat, GO signal, emergency stop).
-   **`serial_protocol.h` / `serial_protocol.cpp`**: Defines the constants for command IDs (e.g., `CMD_SET_MOTOR_SPEED`, `CMD_ALL_SENSOR_DATA_COMPACT`) and packet structure. It provides utility functions for calculating checksums (`calculateChecksum`) and creating packets (`createPacket`), ensuring consistent communication protocol implementation.

### 2.4. Sensors (`src/sensors/`)

-   **`sensor_data.h`**: Defines the `SensorData` struct, which mirrors the `CompactSensorData` struct on the Nano. This struct efficiently packs ultrasonic distance readings (front, right, back, left) and scaled IMU data (accelerometer X/Y/Z, gyroscope X/Y/Z) into a 20-byte binary format for fast transmission.
-   **`sensor_fusion.h` / `sensor_fusion.cpp`** _(Currently Placeholder)_: Intended for combining data from multiple sensors (IMU, ultrasonics) to produce a more robust estimate of the vehicle's state (position, orientation, velocity). This is crucial for accurate navigation and lap counting.

### 2.5. Vision (`src/vision/`)

This subsystem handles image capture and processing for detecting track features like traffic signs and edges.

-   **`frame_buffer.h` / `frame_buffer.cpp`**: A thread-safe buffer designed for efficient streaming of image frames from the capture thread to the processing thread. It holds only the _latest_ frame, minimizing latency and memory usage.
-   **`camera_interface.h` / `camera_interface.cpp`**: Manages the connection to the Pi Camera Module via V4L2 (using OpenCV). It initializes the camera, sets resolution and frame rate, and runs a background thread (`captureLoop`) to continuously capture frames and place them into the `FrameBuffer`.
-   **`image_processor.h` / `image_processor.cpp`**: The core of the vision system. It retrieves frames from the `FrameBuffer`, processes them (converts to HSV, applies ROI), and performs basic color blob detection for Red/Green signs and simplified edge detection (using thresholding and column sum analysis). It outputs a `VisionSnapshot` struct containing the results (signs detected, approximate edge positions).
-   **`color_detector.h` / `color_detector.cpp`**, **`edge_detector.h` / `edge_detector.cpp`**, **`roi_selector.h` / `roi_selector.h`**, **`line_follower.h` / `line_follower.cpp`** _(Currently Empty Placeholders)_: These files are intended to decompose the monolithic `image_processor.cpp` logic into more specialized modules for better modularity and clarity in future development.

### 2.6. Navigation (`src/navigation/`)

This layer is responsible for understanding the vehicle's position and progress within the challenge.

-   **`mission_state.h` / `mission_state.cpp`**: Encapsulates the overall state of the mission, including the challenge type (Open/Obstacle), the current phase (Pre-Start, Driving, Parking, Stopping), the start position (Regular/Parking Lot), and the current lap number. This state is used by other modules to make decisions.
-   **`positional_memory.h` / `positional_memory.cpp`**: Stores sensor and vision snapshots of key positions (initial start, pre-stop position, parking entrance). It provides methods to compare the current state with these stored states using simple similarity metrics (based on US distances and vision features). This is critical for tasks like stopping the vehicle in the exact starting position.
-   **`lap_counter.h` / `lap_counter.cpp`**: Tracks the number of laps completed. It uses sensor data (primarily IMU for rotation and US for distance estimation) and potentially vision data to detect transitions between track sections and determine when a full lap (8 sections) has been completed, ensuring the vehicle has left and returned to the start zone.
-   **`course_map.h` / `course_map.cpp`**, **`sign_detector.h` / `sign_detector.cpp`** _(Currently Empty Placeholders)_: `course_map` would build a representation of the known/observed track layout. `sign_detector` would be a dedicated module for interpreting vision data to robustly identify and classify traffic signs, separating this logic from `image_processor`.

### 2.7. Control (`src/control/`)

This layer translates navigation decisions into actionable commands.

-   **`path_planner.h` / `path_planner.cpp`**: The high-level decision-making module. Based on the `MissionState`, `LapCounter` data, and `VisionSnapshot`, it determines the vehicle's next action (e.g., `FOLLOW_LEFT_LANE`, `FOLLOW_RIGHT_LANE`, `GO_STRAIGHT`, `STOP_IN_START`, `EXECUTE_PARKING`). It implements basic obstacle avoidance logic.
-   **`vehicle_controller.h` / `vehicle_controller.cpp`**: The actuator interface. It receives `NavigationCommand`s from the `PathPlanner` and translates them into specific motor speed (int8_t) and servo angle (uint8_t) commands, sending them via the `SerialHandler`. It also manages complex maneuvers like the parallel parking sequence, taking over control until the maneuver is complete.
-   **`parking_assistant.h` / `parking_assistant.cpp`**, **`trajectory_generator.h` / `trajectory_generator.cpp`** _(Currently Empty Placeholders)_: `parking_assistant` would contain the detailed logic for the parking maneuver, potentially separating it from `vehicle_controller`. `trajectory_generator` would be an optional intermediate step to calculate smooth speed/steering profiles from path plans.

### 2.8. Actuators (`src/actuators/`)

-   **`vehicle_controller.h` / `vehicle_controller.cpp`** _(See Control section above)_: This is the primary actuator control module.

### 2.9. Utilities (`src/utils/`)

-   **`logger.h`**, **`timer.h` / `timer.cpp`**, **`math_utils.h`** _(Currently Empty Placeholders)_: Utility modules for logging debug information, measuring execution time, and providing common mathematical functions. Essential for development, debugging, and performance optimization.

## 3. Data Flow & Interaction

1.  **Initialization:** `main.cpp` initializes all modules and establishes dependencies (e.g., passes `SerialHandler` to `VehicleController`).
2.  **Background Tasks:**
    -   `CameraInterface` runs `captureLoop` to feed frames to `FrameBuffer`.
    -   `ImageProcessor` runs `processingLoop` to consume frames from `FrameBuffer` and produce `VisionSnapshot`.
    -   `SerialHandler` runs `receiveLoop` to consume bytes from the serial port, parse packets, and update its internal `SensorData` buffer.
3.  **Main Loop (`main.cpp`):**
    -   Retrieves latest `SensorData` from `SerialHandler`.
    -   Retrieves latest `VisionSnapshot` from `ImageProcessor`.
    -   Updates `LapCounter` with new data.
    -   Updates `MissionState` based on events (e.g., receiving `START_ACK` from Nano).
    -   Calls the appropriate phase handler (`handleDriving`, `handleStoppingAtStart`, etc.) based on `MissionState`.
    -   The phase handler (e.g., `handleDriving`) calls `PathPlanner::plan()` with current data and state.
    -   `PathPlanner` returns a `NavigationCommand`.
    -   The phase handler passes this command to `VehicleController::executeCommand()`.
    -   `VehicleController` sends the corresponding low-level commands to the Nano via `SerialHandler`.
    -   Sends periodic heartbeat to Nano.

## 4. Building the Software

This project uses CMake for building.

### Prerequisites

-   **Raspberry Pi OS (or compatible Linux)**
-   **CMake** (version 3.10 or higher): `sudo apt update && sudo apt install cmake`
-   **OpenCV Development Libraries**: `sudo apt install libopencv-dev`
-   **Git** (for version control, assumed): `sudo apt install git`

### Build Steps

1.  **Navigate to the Project Root:** Open a terminal and go to the directory containing this `README.md` file (e.g., `/home/user/WRO_2025/coding_part/wro2025_vehicle`).
2.  **Create a Build Directory:** It's good practice to build outside the source tree.
    ```bash
    mkdir build
    cd build
    ```
3.  **Configure the Build:** Run CMake from within the `build` directory, pointing it to the parent directory where `CMakeLists.txt` resides.
    ```bash
    cmake ..
    ```
4.  **Compile:** Use `make` to compile the project.
    ```bash
    make
    ```
5.  **Run:** If compilation is successful, the executable (named `WRO2025_Vehicle_Controller` based on the `CMakeLists.txt` provided earlier) will be created in the `build` directory. Run it from the terminal.
    ```bash
    ./WRO2025_Vehicle_Controller
    ```

## 5. Relationship to Electromechanical Components

-   **Raspberry Pi Zero 2W:** Runs this entire software stack. It receives processed sensor data and sends high-level commands.
-   **Pi Camera Module (CSI):** The source of image data for the `vision` modules.
-   **Arduino Nano:** Runs the real-time control firmware. Receives motor/servo commands via serial from this Pi software and sends back sensor data.
-   **MPU6050 IMU, Ultrasonic Sensors:** Their data is read by the Nano, packaged, and sent to the Pi via the serial link for processing by `sensors` and `navigation` modules.
-   **L298N Motor Driver, Servo Motor:** Controlled by the Nano based on commands received from this Pi software via the serial link.

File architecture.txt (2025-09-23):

wro2025_nano_firmware/
├── src/
│   ├── main.ino                # Setup, loop, state machine
│   ├── config.h                # Pin definitions, sensor addresses, motor parameters
│   ├── sensors/                # Sensor reading functions
│   │   ├── imu_handler.h       # MPU6050 setup, read, data processing (DMP or basic fusion)
│   │   ├── imu_handler.cpp
│   │   ├── us_sensor_array.h   # Array of ultrasonic sensors, read distances
│   │   └── us_sensor_array.cpp
│   ├── actuators/              # Motor/Servo control functions
│   │   ├── motor_controller.h  # L298N control functions (set speed/direction)
│   │   ├── motor_controller.cpp
│   │   ├── servo_controller.h  # Steering servo control
│   │   └── servo_controller.cpp
│   ├── communication/          # Serial communication handler
│   │   ├── serial_protocol.h   # Same packet definitions as Pi
│   │   ├── serial_parser.h     # Parses incoming commands, builds outgoing data packets
│   │   └── serial_parser.cpp
│   ├── safety/                 # Fallback mechanisms
│   │   ├── watchdog.h          # Timer, expects periodic "heartbeat" from Pi
│   │   ├── watchdog.cpp
│   │   ├── e_stop.h            # Handles emergency stop command
│   │   └── e_stop.cpp
│   └── utils/                  # Utility functions (e.g., CRC calculation)
│       └── crc8.h
└── platformio.ini              # PlatformIO project configuration (if used)

and 

wro2025_vehicle/
├── src/
│   ├── main.cpp                     # Entry point, initializes modules, main loop
│   ├── config/                      # Configuration files or headers
│   │   └── vehicle_config.h         # Physical dimensions, sensor pins, thresholds, etc.
│   ├── communication/               # Handles serial communication with Nano
│   │   ├── serial_protocol.h        # Defines packet structure, commands, IDs
│   │   ├── serial_protocol.cpp
│   │   ├── serial_handler.h         # Manages sending/receiving packets
│   │   └── serial_handler.cpp
│   ├── sensors/                     # Processes data received from Nano
│   │   ├── sensor_data.h            # Structs for IMU, Ultrasonics data
│   │   ├── sensor_fusion.h          # Combines sensor data (optional but useful)
│   │   └── sensor_fusion.cpp
│   ├── navigation/                  # Core logic modules
│   │   ├── course_map.h             # Represents track state (walls, signs)
│   │   ├── course_map.cpp
│   │   ├── lap_counter.h            # Logic for counting laps based on position
│   │   ├── lap_counter.cpp
│   │   ├── sign_detector.h          # Interprets sign positions from camera/course_map
│   │   └── sign_detector.cpp
│   ├── control/                     # Decision-making logic
│   │   ├── path_planner.h           # High-level path planning (where to go)
│   │   ├── path_planner.cpp
│   │   ├── trajectory_generator.h   # Calculates desired speed/steering (optional intermediate step)
│   │   ├── trajectory_generator.cpp
│   │   ├── parking_assistant.h      # Logic for finding parking spot and executing maneuver
│   │   └── parking_assistant.cpp
│   ├── actuators/                   # Sends commands based on decisions
│   │   ├── vehicle_controller.h     # Translates high-level commands to motor/servo cmds
│   │   └── vehicle_controller.cpp
│   ├── vision/                      # Image processing modules
│   │   ├── camera_interface.h       # Wrapper for camera capture (e.g., using libcamera or V4L2)
│   │   ├── camera_interface.cpp
│   │   ├── image_processor.h        # Core image processing logic
│   │   ├── image_processor.cpp
│   │   ├── roi_selector.h           # Defines and manages Region of Interest
│   │   ├── roi_selector.cpp
│   │   ├── color_detector.h         # Detects red/green signs within ROI
│   │   ├── color_detector.cpp
│   │   ├── edge_detector.h          # Detects track edges/lines within ROI
│   │   ├── edge_detector.cpp
│   │   ├── line_follower.h          # Logic based on edge detection (if used)
│   │   └── line_follower.cpp
│   └── utils/                       # Utility functions, math helpers, timers
│       ├── timer.h
│       ├── timer.cpp
│       ├── math_utils.h
│       └── logger.h                 # Simple logging for debugging
├── include/                         # Public headers for libraries/modules (if needed)
├── lib/                             # External libraries (e.g., OpenCV C++ headers/libs if not system-wide)
├── build/                           # Build artifacts (created by CMake/make)
├── CMakeLists.txt                   # Build configuration file (recommended for C++)
├── docs/                            # Documentation files (for GitHub)
│   └── README.md                    # Main documentation file (5000+ chars required)
├── scripts/                         # Helper scripts (e.g., for camera setup, running the program)
│   └── run_vehicle.sh
├── videos/                          # Performance videos (for GitHub)
├── photos/                          # Vehicle/team photos (for GitHub)
└── LICENSE                          # License file (if applicable, good practice)

wro2025_vehicle_python/
├── config/
│   ├── __init__.py
│   └── vehicle_config.py         # Constants (serial port, camera params, etc.)
├── communication/
│   ├── __init__.py
│   └── serial_handler.py         # Python implementation using pyserial
├── sensors/
│   ├── __init__.py
│   └── sensor_data.py            # Define SensorData/CompactSensorData classes/structs (using ctypes or dataclasses)
├── vision/
│   ├── __init__.py
│   ├── camera_interface.py       # Manage rpicam-vid subprocess, capture JPEGs
│   ├── frame_buffer.py           # Thread-safe queue for frames (e.g., queue.Queue)
│   ├── image_processor.py        # Core image processing logic (ColorDetector, EdgeDetector classes)
│   ├── color_detector.py         # Specific color detection logic
│   ├── edge_detector.py          # Specific edge detection logic
│   └── vision_snapshot.py        # Define VisionSnapshot dataclass
├── navigation/
│   ├── __init__.py
│   ├── mission_state.py          # MissionPhase, ChallengeType enums, state management
│   ├── lap_counter.py            # Lap counting logic
│   ├── positional_memory.py      # Positional memory logic
│   └── path_planner.py           # Path planning logic (Open/Obstacle)
├── control/
│   ├── __init__.py
│   ├── path_planner.py           # (Might merge with navigation/path_planner.py or keep separate logic)
│   └── trajectory_generator.py   # Trajectory generation logic
├── actuators/
│   ├── __init__.py
│   └── vehicle_controller.py     # Interface to send commands via serial
├── utils/
│   ├── __init__.py
│   ├── logger.py                 # Logging setup (can use Python's logging module)
│   └── math_utils.py             # Math helper functions
├── main.py                       # Main application loop, initializes modules, runs states
├── requirements.txt              # List Python dependencies (opencv-python, pyserial, etc.)
└── scripts/
    └── run_vehicle.sh            # Optional script to run the application

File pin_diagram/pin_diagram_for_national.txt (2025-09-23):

Okay, let's clarify the wiring based on your `config.h` file. This assumes you are using an **Arduino Nano** as your main controller, as indicated by the pin numbers used (e.g., A0, A1, A4, A5).

Here is the crystal-clear wiring plan derived from your configuration:

**1. Power Supply Connections (Essential First Step)**

*   **Battery Pack Positive (+)** -> **L298N VCC** (Motor Power Input)
*   **Battery Pack Negative (-)** -> **L298N GND** (Motor Ground) **AND** -> **Arduino Nano GND** (Common Ground)
*   **L298N 5V Output** (if used) -> **Arduino Nano Vin** (Optional, if L298N's onboard 5V regulator is used. If using a separate 5V regulator/buck converter for Nano/SENSORS, connect that 5V/GND to Nano's 5V/GND pins).
*   **Important:** Ensure the grounds of your battery packs (motor and logic, if separate) are connected together.

**2. Ultrasonic Sensors**

Each HC-SR04 sensor has four pins: VCC, Trig, Echo, GND.

| Sensor Name | VCC Pin | Trig Pin | Echo Pin | GND Pin |
| :--- | :--- | :--- | :--- | :--- |
| **Front** | **5V** (Nano) | **D3** (Nano Pin 5)  | **D4** (Nano Pin 6)  | **GND** (Nano) |
| **Right** | **5V** (Nano) | **D5** (Nano Pin 11) | **D6** (Nano Pin 12) | **GND** (Nano) |
| **Back** | **5V** (Nano) | **D7** (Nano Pin 13) | **D8** (Nano Pin 14) | **GND** (Nano) |
| **Left** | **5V** (Nano) | **D9** (Nano Pin 15) | **D10** (Nano Pin 16)| **GND** (Nano) |

**3. L298N Motor Driver**

Connect the L298N to the Nano and the motors.

| L298N Pin | Connection |
| :--- | :--- |
| **ENA** | **D12** (Nano Pin 19) |
| **IN1** | **D13** (Nano Pin 17) |
| **IN2** | **A0** (Nano Pin 23) |
| **IN3** | **Not Connected** (Single Motor) |
| **IN4** | **Not Connected** (Single Motor) |
| **ENB** | **Not Connected** (Single Motor) |
| **VCC** | **+ve Battery Pack Terminal**  |
| **GND** | **-ve Battery Pack Terminal**  |
| **5V** | **(See Power Supply Note)** |
| **OUT1**  | **One Terminal of Rear Motor**|
| **OUT2**  | **Other Terminal of Rear Motor** |
| **5V/GND** (Logic Power) | **5V/GND from Nano's power source** |

**4. Servo Motor (Steering)**

Typically, a servo has three wires: Power (Red/Brown), Ground (Black/Brown), Signal (Orange/Yellow/White).

| Servo Wire | Connection |
| :--- | :--- |
| **Power (Red/Brown)** | **5V** (Nano or dedicated servo power) |
| **Ground (Black/Brown)** | **GND** (Nano, connected to motor ground) |
| **Signal (Orange/Yellow/White)** | **D11** (Nano Pin 16) |

**5. IMU (MPU6050)**

Uses the I2C bus on the Nano.

| MPU6050 Pin | Connection |
| :--- | :--- |
| **VCC** | **3.3V** (Nano) |
| **GND** | **GND** (Nano) |
| **SCL** | **A5** (Nano Pin 28) |
| **SDA** | **A4** (Nano Pin 27) |
| **XDA/XCL** | **(Usually Not Connected)** |
| **ADO** | **(Usually GND for default address 0x68)** |
| **INT** | **(Optional, Not Used in Provided Config)** |

**6. Start Button**

A simple push-button.

| Button Terminal 1 | **D2** (Nano Pin 4) |
| Button Terminal 2 | **GND** (Nano)     |
*(Note: Your code likely uses `pinMode(START_BUTTON_PIN, INPUT_PULLUP);`, so no external pull-up resistor is needed.)*

**7. Status LED (Optional)**

A simple LED for debugging.

| LED Anode (Long Leg) | **A1** (Nano Pin 24) via a ~220-330 Ohm resistor |
| LED Cathode (Short Leg) | **GND** (Nano) |

**Visual Representation (Conceptual)**

Imagine your Arduino Nano board:

*   **Digital Pins (D0-D13, A0-A5):**
    *   **D2:** Start Button (other side to GND)
    *   **D3:** US Front Trig
    *   **D4:** US Front Echo
    *   **D5:** US Right Trig
    *   **D6:** US Right Echo
    *   **D7:** US Back Trig
    *   **D8:** US Back Echo
    *   **D9:** US Left Trig
    *   **D10:** US Left Echo
    *   **D11:** Servo Signal
    *   **D12:** L298N ENA
    *   **D13:** L298N IN1
    *   **A0:** L298N IN2
    *   **A1:** Status LED (Anode via resistor)
    *   **A4 (SDA):** MPU6050 SDA
    *   **A5 (SCL):** MPU6050 SCL
*   **Power Pins:**
    *   **5V:** Connect to VCC of US Sensors, Servo, L298N Logic (VCC/GND pins), Status LED Cathode (via resistor).
    *   **3.3V:** Connect to VCC of MPU6050.
    *   **GND:** Connect to GND of US Sensors, Servo, MPU6050, L298N, Start Button (one side), Status LED Cathode.

**Important Notes:**

*   **Power:** Ensure your power supply (battery pack) can handle the current draw of the motors and other components. The L298N handles motor power, while the Nano/SENSORS need a stable 5V (or 3.3V for Nano/MPU6050). If using a buck converter, connect its output 5V/GND to the Nano's 5V/GND pins and sensor VCC/GND.
*   **Common Ground:** It's crucial that the ground of your motor battery pack is connected to the ground of your Nano's power supply. This is the reference point for all signals.
*   **Signal Voltage:** The Nano operates at 5V logic. Most sensors (including HC-SR04) are 5V tolerant. The MPU6050 typically runs at 3.3V, so connecting it to the Nano's 3.3V pin is correct. Be cautious if mixing 3.3V and 5V devices.
*   **L298N Connections:** The specific connections for OUT1/OUT2 depend on your motor and how you want it to rotate. Swapping them reverses the motor direction.
*   **Servo Power:** If your servo draws significant current, consider powering it from the battery pack directly (VCC/GND) rather than through the Nano, to avoid brownouts. Connect the signal wire to D11.

This plan directly corresponds to the pin definitions in your `config.h` file.

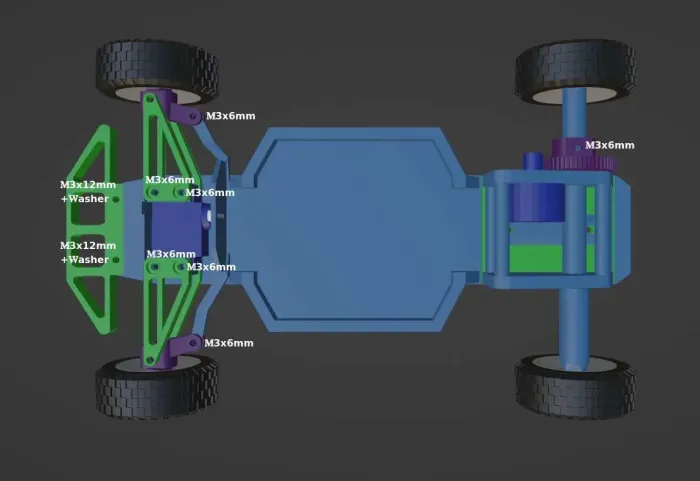
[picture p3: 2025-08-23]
RC Chassis/model.webp

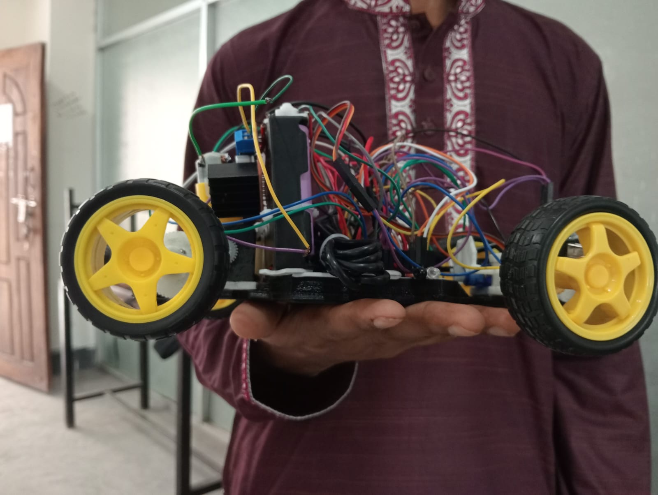
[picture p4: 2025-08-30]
Pictures/right.jpeg

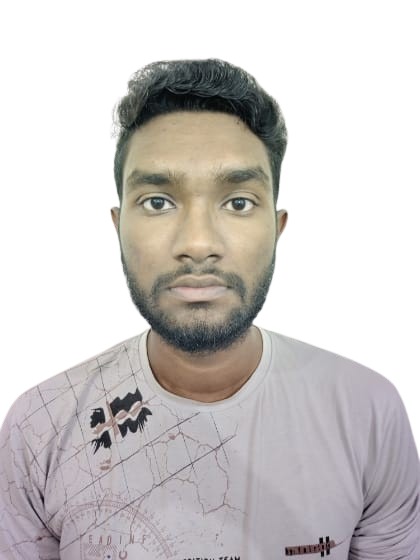
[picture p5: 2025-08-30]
Pictures/rohit.jpeg

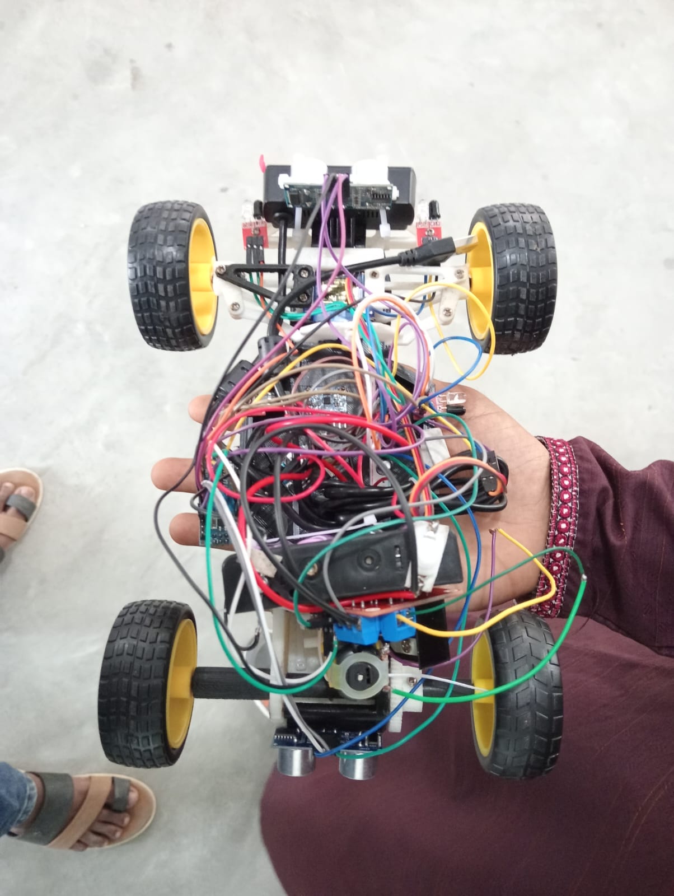
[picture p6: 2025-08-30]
Pictures/up.jpeg

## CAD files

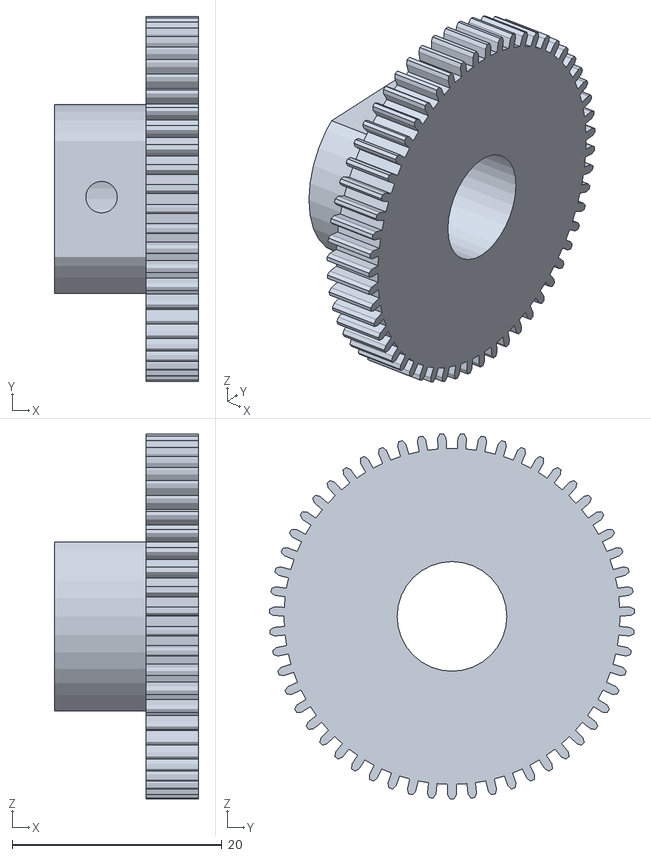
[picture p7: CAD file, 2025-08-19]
RC Chassis/Main Gear.stl
13.7 x 34.8 x 34.8

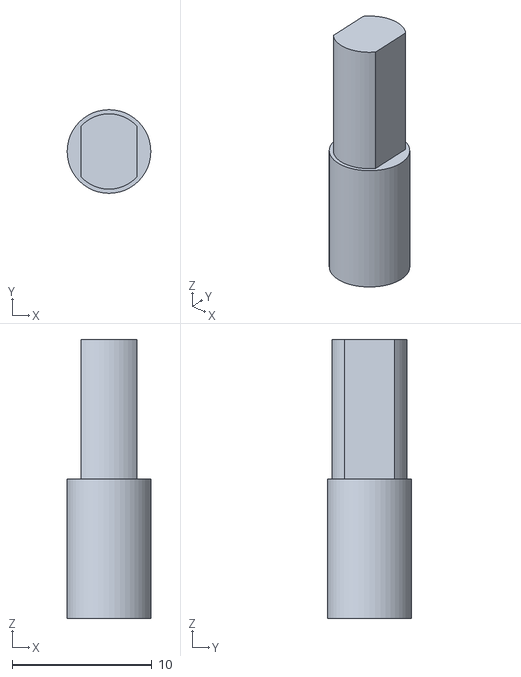
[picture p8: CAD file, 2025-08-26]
RC Chassis/Super Stantia-Hango.stl
6.00 x 6.00 x 20.0

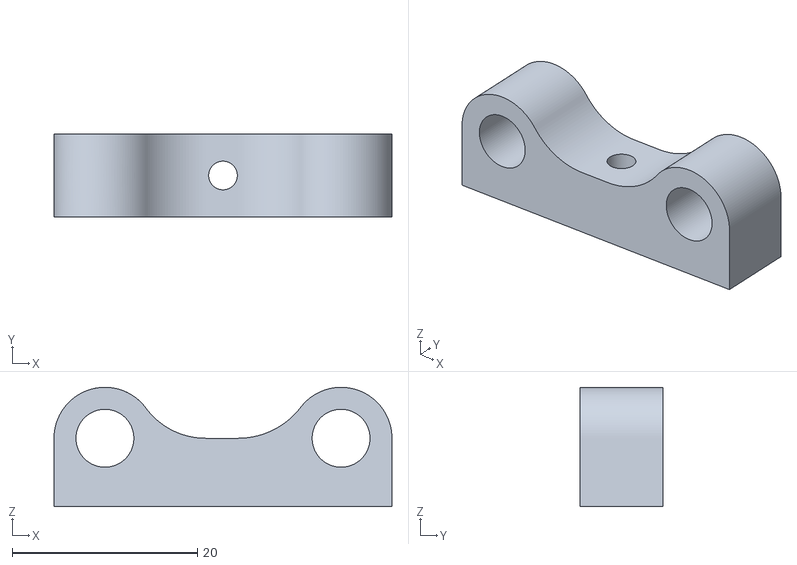
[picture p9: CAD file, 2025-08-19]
simple-rc-car-1.snapshot.8/AxisHolder.stl
36.5 x 9.00 x 12.9

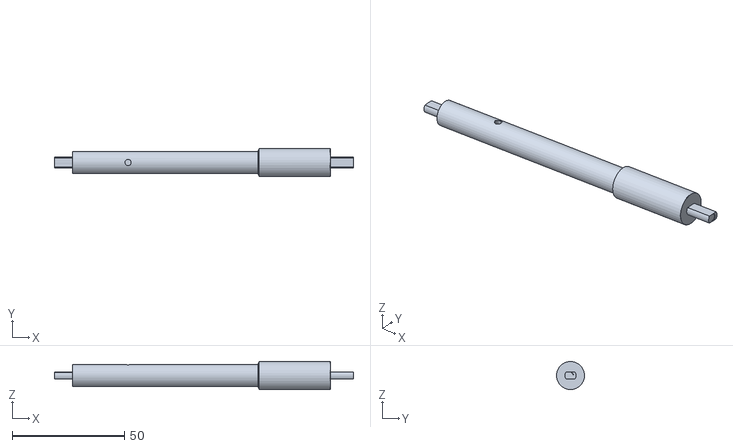
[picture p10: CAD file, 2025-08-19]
RC Chassis/rear_shaft.stl
133.3 x 12.5 x 12.5

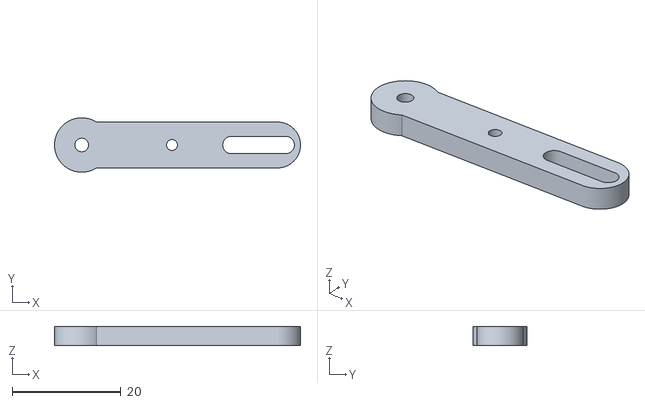
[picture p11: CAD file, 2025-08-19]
simple-rc-car-1.snapshot.8/ServoArmExtender.stl
45.2 x 10.00 x 3.50

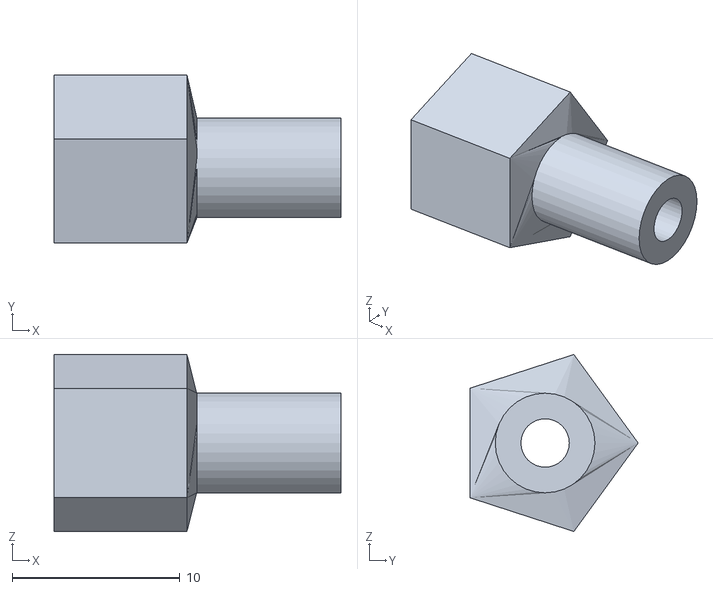
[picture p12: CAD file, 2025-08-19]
RC Chassis/Hub.stl
17.1 x 10.0 x 10.5

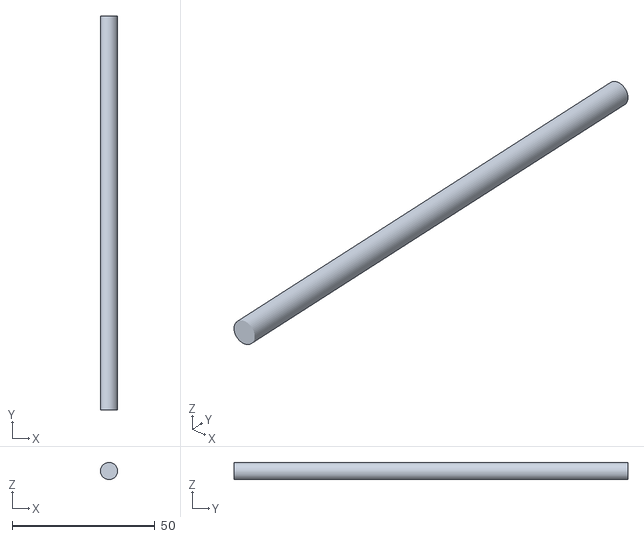
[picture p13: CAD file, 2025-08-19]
simple-rc-car-1.snapshot.8/BackAxis.stl
5.99 x 138.0 x 6.00

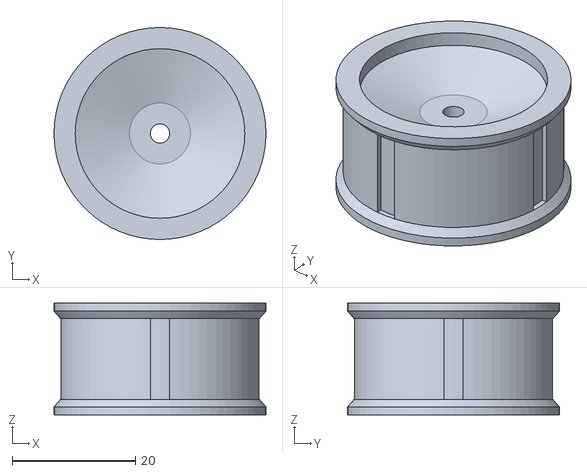
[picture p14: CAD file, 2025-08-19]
RC Chassis/Rim.stl
34.3 x 34.3 x 18.1

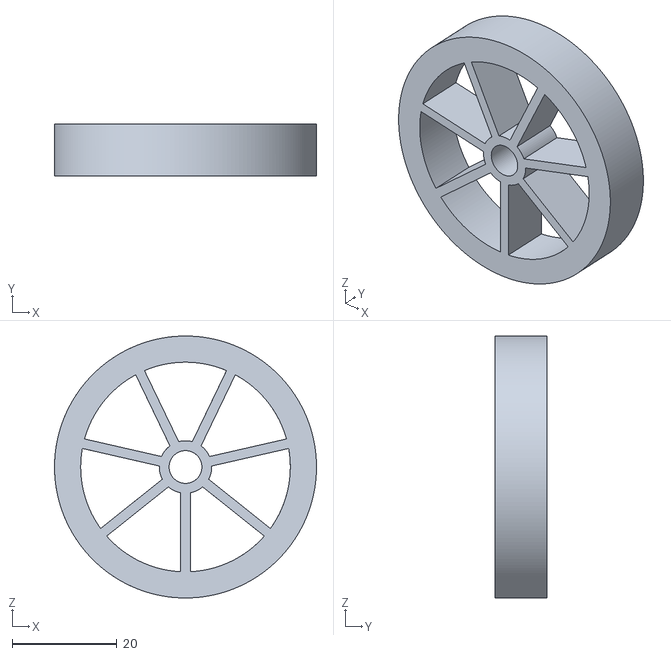
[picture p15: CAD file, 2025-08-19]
simple-rc-car-1.snapshot.8/frontWheelx2.stl
50.0 x 10.0 x 50.0

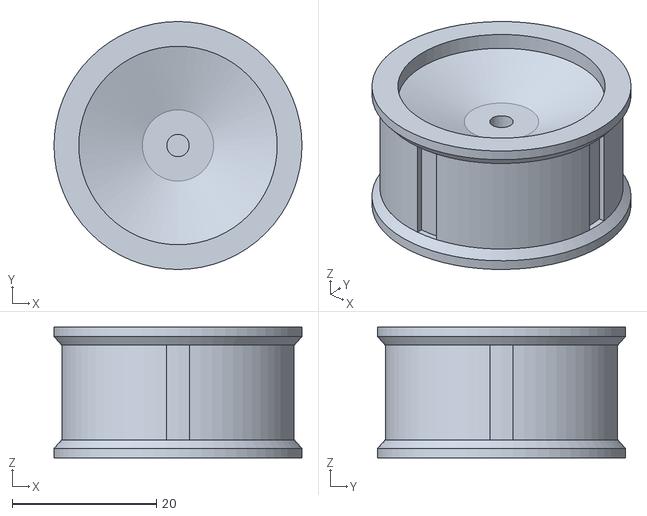
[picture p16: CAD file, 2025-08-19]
RC Chassis/Rim no support needed.stl
34.3 x 34.3 x 18.1

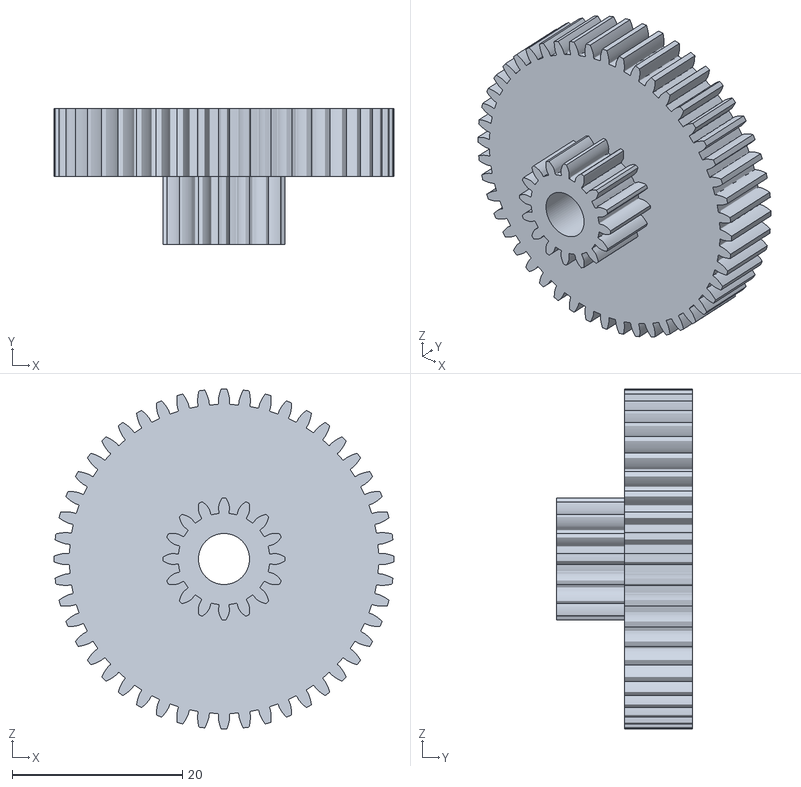
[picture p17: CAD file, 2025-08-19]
simple-rc-car-1.snapshot.8/midGear.stl
40.0 x 16.0 x 40.0

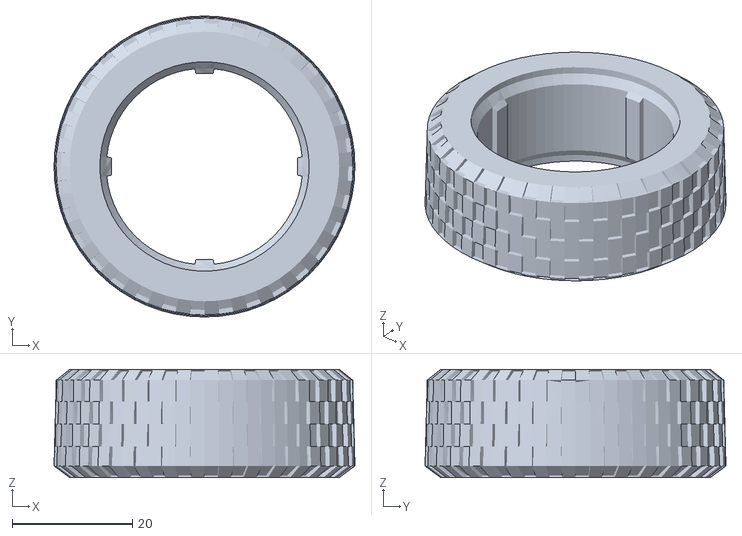
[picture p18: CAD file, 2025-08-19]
RC Chassis/wheel.stl
50.0 x 50.0 x 18.0

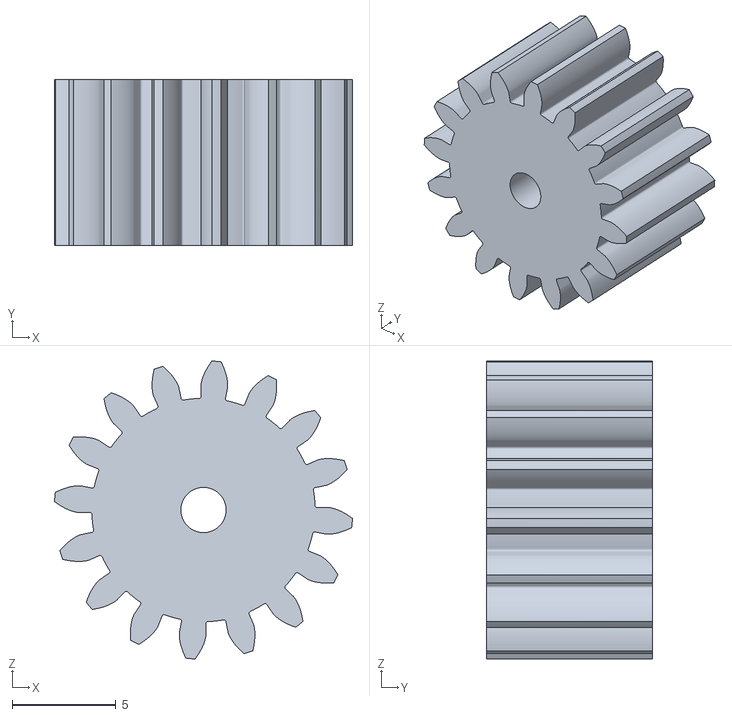
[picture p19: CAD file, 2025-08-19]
simple-rc-car-1.snapshot.8/DcMotorGear.stl
14.4 x 8.00 x 14.4

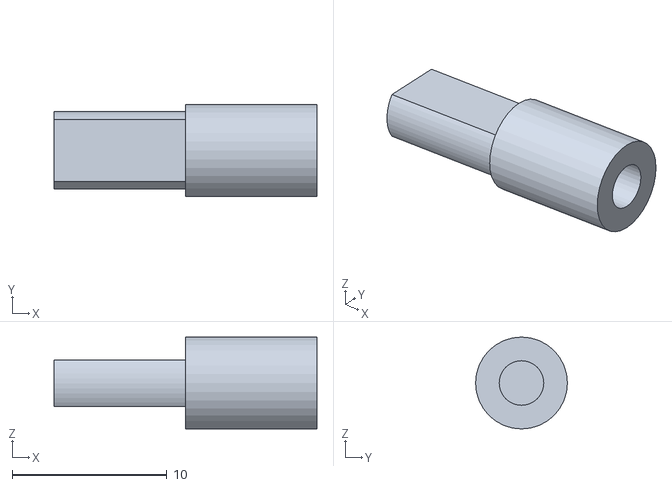
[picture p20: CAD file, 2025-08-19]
RC Chassis/front_wheel_holder.stl
17.0 x 5.94 x 5.94

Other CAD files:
simple-rc-car-1.snapshot.8/TopFront Holder.stl
RC Chassis/Bumper.stl
simple-rc-car-1.snapshot.8/WheelHolder.stl
RC Chassis/Servo mount.stl
RC Chassis/Axles.stl
RC Chassis/Control arm.stl
RC Chassis/Copy of Copy of Copy of 4_wd.stl
RC Chassis/Low front shock absorber.stl
RC Chassis/Motor mount A.stl
RC Chassis/Motor mount B.stl
RC Chassis/Pinion gear.stl
RC Chassis/Rear shock absorber.stl
RC Chassis/Steering rod.stl
RC Chassis/Tire.stl
RC Chassis/Upper left front shock absorb.stl
RC Chassis/Upper right front shock absor.stl
RC Chassis/frame.stl
RC Chassis/front_wheeler.stl
RC Chassis/wheel_no_support.stl
simple-rc-car-1.snapshot.8/AxisRingsx6.stl
simple-rc-car-1.snapshot.8/Back Wheelx2.stl
simple-rc-car-1.snapshot.8/BackGear.stl
simple-rc-car-1.snapshot.8/KitronicLowInertiaMotor.stl
simple-rc-car-1.snapshot.8/MicroBitHolder.stl
simple-rc-car-1.snapshot.8/ServoArm.stl
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

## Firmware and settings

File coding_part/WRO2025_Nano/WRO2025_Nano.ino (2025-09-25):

// WRO2025_Nano.ino
// Main application for WRO 2025 Nano controller

// Include standard libraries
#include <NewPing.h>
#include <Servo.h>
#include <Wire.h>

// Include project configuration
#include "config.h"

// Include all module headers
#include "imu_handler.h"
#include "us_sensor_array.h"
#include "motor_controller.h"
#include "servo_controller.h"
#include "serial_protocol.h"
#include "serial_parser.h"
#include "watchdog.h"
#include "e_stop.h"

// --- Module instances ---
IMUHandler imuHandler;
USSensorArray usSensorArray;
MotorController motorController;
ServoController servoController;
SerialParser serialParser;
Watchdog watchdog;
EStopHandler eStopHandler;

// --- Global State variables ---
bool isStarted = false;         // Has the START button been pressed?
bool missionGoReceived = false; // Has the Pi sent the "GO" command?
unsigned long lastUSTime = 0;
unsigned long lastIMUTime = 0;
int motorSpeed = 0;
int servoAngle = SERVO_CENTER_ANGLE;
unsigned long lastHighSpeedSensorTime = 0;
const unsigned long HIGH_SPEED_SENSOR_INTERVAL = 50; // Send combined data every 50ms (20 Hz)

// Sensor data structures
IMUData currentIMUData;
USSensorData currentUSData;

// --- Function prototypes (good practice for Arduino IDE) ---
void processSerialCommands();

void setup()
{
    // Initialize serial communication
    Serial.begin(SERIAL_BAUD_RATE);

    // Initialize all modules
    imuHandler.initialize();
    usSensorArray.initialize(
        US_FRONT_TRIG_PIN, US_FRONT_ECHO_PIN,
        US_RIGHT_TRIG_PIN, US_RIGHT_ECHO_PIN,
        US_BACK_TRIG_PIN, US_BACK_ECHO_PIN,
        US_LEFT_TRIG_PIN, US_LEFT_ECHO_PIN);

    motorController.initialize(MOTOR_ENA_PIN, MOTOR_IN1_PIN, MOTOR_IN2_PIN);
    servoController.initialize(SERVO_PIN);

    watchdog.initialize(WATCHDOG_TIMEOUT);
    eStopHandler.initialize();

    // Setup start button with internal pull-up
    pinMode(START_BUTTON_PIN, INPUT_PULLUP);

    // Setup status LED
    pinMode(STATUS_LED_PIN, OUTPUT);
    digitalWrite(STATUS_LED_PIN, LOW);

    // Small delay to allow sensors to stabilize
    delay(100);

    // Calibrate IMU (this will take some time)
    // In a competition setting, you might want to do this during preparation time
    // rather than during the setup phase
    imuHandler.calibrate();

    // Indicate setup complete
    digitalWrite(STATUS_LED_PIN, HIGH);
    delay(100);
    digitalWrite(STATUS_LED_PIN, LOW);
    // Reset timers to start fresh after setup indication
    lastUSTime = millis();
    lastIMUTime = millis();
    lastHighSpeedSensorTime = millis();
}

void loop()
{
    // --- PRE-START PHASE ---
    // Wait for the physical start button press
    if (!isStarted)
    {
        // Continuously process commands (e.g., heartbeat to keep watchdog happy)
        processSerialCommands();

        // Check for the physical start button press
        if (digitalRead(START_BUTTON_PIN) == LOW)
        {              // Assuming pull-up, LOW = pressed
            delay(20); // Debounce
            if (digitalRead(START_BUTTON_PIN) == LOW)
            { // Check again after debounce
                Serial.println("Nano: Physical START button pressed and debounced.");
                isStarted = true;
                digitalWrite(STATUS_LED_PIN, HIGH); // Visual confirmation

                // Send start acknowledgment to Pi
                serialParser.sendStartAck(true);

                // Reset timestamps for immediate sensor reads on start
                lastUSTime = millis();
                lastIMUTime = millis();
                lastHighSpeedSensorTime = millis();

                // Do not 'return' here, let the loop continue to the operational phase
                // The state change (isStarted = true) will take effect next iteration
            }
        }
        // If not started, ONLY processSerialCommands and check button
        return; // Exit loop early, wait for next iteration
    }

    // --- OPERATIONAL PHASE (isStarted == true) ---

    // 1. Process incoming serial commands (Priority 1: React to commands immediately)
    processSerialCommands();

    // 2. Wait for explicit GO command from Pi before doing main tasks
    if (!missionGoReceived)
    {
        // We are started (button pressed) but waiting for Pi's GO signal.
        // Only processSerialCommands and watchdog (for safety) are active.
        // Check watchdog even in this state to catch communication loss immediately
        if (watchdog.isExpired())
        {
            eStopHandler.activateEStop();
        }
        delay(10); // Small delay to prevent busy-waiting
        return;    // Do not proceed with sensors/actuators until GO received
    }

    // --- MAIN OPERATIONAL LOOP (runs only AFTER missionGoReceived == true) ---
    unsigned long currentTime = millis();

    // 3. Read sensors at defined intervals
    // Read ultrasonic sensors
    if (currentTime - lastUSTime > US_MEASURE_INTERVAL)
    {
        if (usSensorArray.readData(currentUSData))
        {
            // Optional: Send individual US updates if needed by Pi logic frequently
            // serialParser.sendSensorData(...);
        }
        lastUSTime = currentTime;
    }

    // Read IMU data (more frequently than US sensors if needed, but we send combined)
    if (currentTime - lastIMUTime > 50)
    {                                        // e.g., 20Hz
        imuHandler.readData(currentIMUData); // Result stored in currentIMUData
        lastIMUTime = currentTime;
    }

    // Send ALL sensor data together at high speed
    if (currentTime - lastHighSpeedSensorTime > HIGH_SPEED_SENSOR_INTERVAL)
    {
        // Prepare the compact data structure
        CompactSensorData compactData;

        // Fill US data (convert from unsigned int to uint16_t)
        compactData.frontDistance = static_cast<uint16_t>(currentUSData.frontDistance);
        compactData.rightDistance = static_cast<uint16_t>(currentUSData.rightDistance);
        compactData.backDistance = static_cast<uint16_t>(currentUSData.backDistance);
        compactData.leftDistance = static_cast<uint16_t>(currentUSData.leftDistance);

        // Fill IMU data (scale floats to integers for compact transmission)
        compactData.accelX = static_cast<int16_t>(currentIMUData.accelX * 1000.0f); // Convert g to milli-g
        compactData.accelY = static_cast<int16_t>(currentIMUData.accelY * 1000.0f);
        compactData.accelZ = static_cast<int16_t>(currentIMUData.accelZ * 1000.0f);
        compactData.gyroX = static_cast<int16_t>(currentIMUData.gyroX * 1000.0f); // Convert deg/s to milli-deg/s
        compactData.gyroY = static_cast<int16_t>(currentIMUData.gyroY * 1000.0f);
        compactData.gyroZ = static_cast<int16_t>(currentIMUData.gyroZ * 1000.0f);
        Serial.println("Nano: Sending CMD_ALL_SENSOR_DATA_COMPACT packet.");
        // --- END ADD ---
        // Send the compact data packet - This is the FASTEST way
        serialParser.sendCompactSensorData(compactData);

        lastHighSpeedSensorTime = currentTime;
    }

    // 4. Update actuators with current values (only if e-stop is not active)
    if (!eStopHandler.isEStopActive())
    {
        motorController.setSpeed(motorSpeed);
        servoController.setAngle(servoAngle);
    }

    // 5. Check watchdog (Priority: Safety)
    if (watchdog.isExpired())
    {
        eStopHandler.activateEStop();
    }

    // Small delay to prevent overwhelming the system
    delay(5);
}

// --- Function Definitions ---

// Function to process incoming serial commands
void processSerialCommands()
{
    Packet packet;

    // Try to read a packet
    if (serialParser.readPacket(packet))
    {
        // Process valid packet
        switch (packet.command)
        {
        case CMD_SET_MOTOR_SPEED:
            if (packet.length >= 1)
            {
                // Convert byte to signed int (-128 to 127 mapped to -255 to 255)
                int8_t speedByte = (int8_t)packet.data[0];
                motorSpeed = map(speedByte, -128, 127, -MOTOR_MAX_SPEED, MOTOR_MAX_SPEED);

                // Feed watchdog when receiving motor commands
                watchdog.feed();
            }
            break;

        case CMD_SET_SERVO_ANGLE:
            if (packet.length >= 1)
            {
                servoAngle = packet.data[0];
                if (servoAngle > SERVO_MAX_ANGLE)
                    servoAngle = SERVO_MAX_ANGLE;
                if (servoAngle < SERVO_MIN_ANGLE)
                    servoAngle = SERVO_MIN_ANGLE;

                // Feed watchdog when receiving servo commands
                watchdog.feed();
            }
            break;

        case CMD_EMERGENCY_STOP:
            eStopHandler.activateEStop();
            break;

        case CMD_HEARTBEAT:
            // Feed the watchdog on heartbeat
            watchdog.feed();
            break;

        case CMD_REQUEST_SENSOR_DATA:
            // Send current US sensor data (consider adding IMU if needed separately)
            serialParser.sendSensorData(
                currentUSData.frontDistance,
                currentUSData.rightDistance,
                currentUSData.backDistance,
                currentUSData.leftDistance);
            break;

        case CMD_PI_GO_SIGNAL:
            // Pi signals the start of the mission run
            if (isStarted)
            { // Only accept GO if button was pressed first (Rule 9.11)
                missionGoReceived = true;
                Serial.println("Nano: CMD_PI_GO_SIGNAL received, missionGoReceived = true.");
                // Optional: Send an ack back to Pi confirming GO received
                // serialParser.sendAck(CMD_PI_GO_SIGNAL); // You'd need to implement sendAck
                // Blink LED quickly to indicate GO
                digitalWrite(STATUS_LED_PIN, !digitalRead(STATUS_LED_PIN));
                delay(50);
                digitalWrite(STATUS_LED_PIN, HIGH); // Ensure LED stays on
            }
            else
            {
                // GO received before button press - protocol error
                serialParser.sendError(0x02); // Define error code, e.g., "GO before START"
            }
            break;

        default:
            // Unknown command, send error
            serialParser.sendError(0x01); // Unknown command error
            break;
        }
    }
}

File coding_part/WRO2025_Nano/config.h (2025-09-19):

// config.h
// Pin definitions and vehicle configuration constants

#ifndef CONFIG_H
#define CONFIG_H

// -----------------------------
// Pin Definitions
// -----------------------------

// Ultrasonic Sensors
#define US_FRONT_TRIG_PIN 3
#define US_FRONT_ECHO_PIN 4
#define US_RIGHT_TRIG_PIN 5
#define US_RIGHT_ECHO_PIN 6
#define US_BACK_TRIG_PIN 7
#define US_BACK_ECHO_PIN 8
#define US_LEFT_TRIG_PIN 9
#define US_LEFT_ECHO_PIN 10

// Motor Driver (L298N)
#define MOTOR_ENA_PIN 12
#define MOTOR_IN1_PIN 13
#define MOTOR_IN2_PIN A0

// Servo Motor
#define SERVO_PIN 11

// IMU (MPU6050) - Uses I2C
// SDA -> A4
// SCL -> A5

// Start Button
#define START_BUTTON_PIN 2

// Status LED (optional, for debugging)
#define STATUS_LED_PIN A1

// -----------------------------
// Vehicle Configuration
// -----------------------------

// Motor configuration
#define MOTOR_MIN_SPEED 0
#define MOTOR_MAX_SPEED 255
#define MOTOR_STOP 0

// Servo configuration
#define SERVO_MIN_ANGLE 0
#define SERVO_MAX_ANGLE 180
#define SERVO_CENTER_ANGLE 90

// Ultrasonic sensor configuration
#define US_MAX_DISTANCE 200     // Maximum distance we want to measure (in cm)
#define US_MEASURE_INTERVAL 100 // Time between measurements (in milliseconds)

// Watchdog configuration
#define WATCHDOG_TIMEOUT 500 // Time in ms to wait for heartbeat before emergency stop

// Communication
#define SERIAL_BAUD_RATE 115200
#define COMMUNICATION_TIMEOUT 1000 // Time in ms to wait for valid packet

#endif // CONFIG_H

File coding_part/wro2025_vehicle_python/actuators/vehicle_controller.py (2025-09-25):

# actuators/vehicle_controller.py
"""Controls the actuators (motors, servos) via commands sent to the Nano."""

import logging
import time
from enum import IntEnum
from typing import TYPE_CHECKING, Optional
from control.navigation_command import NavigationAction
if TYPE_CHECKING:
    from communication.serial_handler import SerialHandler
    from control.navigation_command import NavigationCommand, NavigationAction
    from sensors.sensor_data import SensorData

logger = logging.getLogger(__name__)

class ParkingState(IntEnum):
    """Represents the state within the parking sequence."""
    APPROACHING_SPOT = 0
    REVERSING_INTO_SPOT = 1
    ADJUSTING_POSITION = 2
    PARKING_COMPLETE = 3
    PARKING_FAILED = 4

class VehicleController:
    """
    Translates high-level NavigationCommands into low-level actuator commands
    sent via the SerialHandler. Manages complex maneuvers like parking.
    """

    def __init__(self, serial_handler: 'SerialHandler'):
        if not serial_handler:
            raise ValueError("VehicleController requires a valid SerialHandler.")
        self.serial_handler = serial_handler

        # Parking state management
        self.parking_active = False
        self.parking_state: ParkingState = ParkingState.APPROACHING_SPOT
        self.parking_step_counter = 0
        self.parking_start_time = 0.0

        # Last sent commands for potential logging or smoothing
        self._last_motor_speed = 0.0
        self._last_servo_angle = 90 # Assume 90 is center

        logger.info("VehicleController initialized.")

    def execute_command(self, command: 'NavigationCommand'):
        """
        Execute a NavigationCommand by sending appropriate motor/servo commands.
        This is the primary interface for the main loop.
        """
        if not command:
            logger.warning("VehicleController: Received None command. Ignoring.")
            return

        action = command.action
        desired_speed = command.desired_speed

        # Handle complex maneuvers first
        if self.parking_active:
            self._execute_parking_step()
            return # Parking takes precedence

        # Map NavigationAction to motor/servo commands
        if action == NavigationAction.GO_STRAIGHT:
            # Speed determines magnitude, servo centered
            motor_speed = self._map_normalized_speed(desired_speed)
            servo_angle = 90 # Straight
            self._send_motor_command(motor_speed)
            self._send_servo_command(servo_angle)

        elif action in (NavigationAction.TURN_LEFT, NavigationAction.FOLLOW_LEFT_LANE):
            motor_speed = self._map_normalized_speed(desired_speed)
            # Negative angle for left turn (assuming 0 is full left, 180 is full right)
            servo_angle = max(0, 90 - 30) # Adjust turn angle as needed
            self._send_motor_command(motor_speed)
            self._send_servo_command(servo_angle)

        elif action in (NavigationAction.TURN_RIGHT, NavigationAction.FOLLOW_RIGHT_LANE):
            motor_speed = self._map_normalized_speed(desired_speed)
            # Positive angle for right turn
            servo_angle = min(180, 90 + 30) # Adjust turn angle as needed
            self._send_motor_command(motor_speed)
            self._send_servo_command(servo_angle)

        elif action == NavigationAction.STOP_IN_START:
            # Gradual stop or immediate stop?
            self._send_motor_command(0)
            self._send_servo_command(90) # Center steering
            logger.info("VehicleController: Executing STOP_IN_START.")

        elif action == NavigationAction.EXECUTE_PARKING:
            # Initiate the parking sequence
            self.start_parking_sequence()

        elif action == NavigationAction.EMERGENCY_STOP:
            self.emergency_stop()
        else:
            logger.warning(f"VehicleController: Unknown action {action}. Stopping.")
            self._send_motor_command(0)
            self._send_servo_command(90)

    def _map_normalized_speed(self, normalized_speed: float) -> int:
        """
        Map a normalized speed (0.0 to 1.0) to an integer motor command (-255 to 255).
        Negative values indicate reverse.
        """
        # Clamp input
        clamped_speed = max(-1.0, min(1.0, normalized_speed))
        # Map to motor range (assuming -255 to 255)
        mapped_speed = int(clamped_speed * 255)
        # Clamp output to motor range if library expects it (pyserial doesn't care)
        return max(-255, min(255, mapped_speed))

    def _send_motor_command(self, speed: int):
        """Send motor speed command via serial handler."""
        if speed != self._last_motor_speed:
            logger.debug(f"VehicleController: Sending motor speed {speed}")
            self.serial_handler.sendMotorSpeedCommand(speed)
            self._last_motor_speed = speed

    def _send_servo_command(self, angle: int):
        """Send servo angle command via serial handler."""
        # Clamp angle to typical servo range if not already
        clamped_angle = max(0, min(180, angle))
        if clamped_angle != self._last_servo_angle:
            logger.debug(f"VehicleController: Sending servo angle {clamped_angle}")
            self.serial_handler.sendServoAngleCommand(clamped_angle)
            self._last_servo_angle = clamped_angle

    # --- Parking Sequence Logic ---

    def start_parking_sequence(self):
        """Initiate the parallel parking sequence."""
        if self.parking_active:
            logger.warning("VehicleController: Parking already active. Cannot start new sequence.")
            return

        logger.info("VehicleController: Starting parallel parking sequence.")
        self.parking_active = True
        self.parking_state = ParkingState.APPROACHING_SPOT
        self.parking_step_counter = 0
        self.parking_start_time = time.time()
        # Reset any previous parking state variables if needed

    def _execute_parking_step(self):
        """Execute the current step of the parking sequence."""
        if not self.parking_active:
            return

        self.parking_step_counter += 1
        current_time = time.time()
        elapsed_time = current_time - self.parking_start_time
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

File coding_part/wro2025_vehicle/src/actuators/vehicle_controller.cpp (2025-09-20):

// actuators/vehicle_controller.cpp
// Implementation of VehicleController

#include "vehicle_controller.h"
#include <iostream>
#include <cmath>  // For round, clamp functions if needed
#include <thread> // For potential small delays if needed
#include <chrono> // For potential small delays if needed

VehicleController::VehicleController()
    : parkingActive(false), maneuverInProgress(false), parkingState(ParkingState::NOT_PARKING), parkingStepCounter(0)
{
    // Constructor initializes atomic flags and member variables
}

bool VehicleController::initialize(std::shared_ptr<SerialHandler> serialHandler)
{
    if (!serialHandler)
    {
        std::cerr << "VehicleController: Invalid SerialHandler provided." << std::endl;
        return false;
    }
    this->serialHandler = serialHandler;
    std::cout << "VehicleController: Initialized with SerialHandler." << std::endl;
    return true;
}

void VehicleController::executeCommand(const NavigationCommand &command)
{
    // If a complex maneuver like parking is active, prioritize its internal logic
    // unless it's an emergency stop.
    if (isManeuverActive() && command.action != NavigationCommand::Action::EMERGENCY_STOP)
    {
        if (parkingActive)
        {
            updateParkingSequence(); // Continue parking logic
        }
        // Ignore other commands while a maneuver is active
        return;
    }

    // Handle the command based on its action
    switch (command.action)
    {
    case NavigationCommand::Action::FOLLOW_LEFT_LANE:
        handleFollowLeftLane(command.desiredSpeed);
        break;
    case NavigationCommand::Action::FOLLOW_RIGHT_LANE:
        handleFollowRightLane(command.desiredSpeed);
        break;
    case NavigationCommand::Action::GO_STRAIGHT:
        handleGoStraight(command.desiredSpeed);
        break;
    case NavigationCommand::Action::STOP_IN_START:
        handleStopInStart();
        break;
    case NavigationCommand::Action::EXECUTE_PARKING:
        handleExecuteParking(); // This starts the parking sequence
        break;
    case NavigationCommand::Action::EMERGENCY_STOP:
        handleEmergencyStop();
        break;
    default:
        // Unknown action, treat as stop or go straight with zero speed?
        std::cerr << "VehicleController: Unknown NavigationCommand action." << std::endl;
        sendMotorCommand(0.0f);
        sendServoCommand(0.0f); // Center steering
        break;
    }
}

void VehicleController::startParkingSequence()
{
    if (isManeuverActive())
    {
        std::cerr << "VehicleController: Cannot start parking, another maneuver is active." << std::endl;
        return;
    }
    parkingActive.store(true);
    maneuverInProgress.store(true);
    parkingState.store(ParkingState::APPROACHING_SPOT);
    parkingStepCounter = 0;
    std::cout << "VehicleController: Starting parking sequence." << std::endl;
}

void VehicleController::updateParkingSequence()
{
    if (!parkingActive)
        return;

    // Simple state machine for parking
    // In a real implementation, this would be much more sophisticated,
    // using encoders, IMU, or precise timing/distance estimates.
    // This is a basic placeholder sequence.

    // Increment step counter (this would ideally be based on time or distance)
    parkingStepCounter++;

    switch (parkingState.load())
    {
    case ParkingState::APPROACHING_SPOT:
        // 1. Approach the spot slowly, aligning the rear axle with the spot start
        sendMotorCommand(0.3f); // Slow forward
        sendServoCommand(0.0f); // Straight
        if (parkingStepCounter > 50)
        { // Placeholder condition
            parkingState.store(ParkingState::REVERSING_IN);
            parkingStepCounter = 0;
            std::cout << "VehicleController: Parking - Reversing into spot." << std::endl;
        }
        break;

    case ParkingState::REVERSING_IN:
        // 2. Start reversing, turn wheels hard right (or left, depending on side)
        sendMotorCommand(-0.4f); // Slow reverse
        sendServoCommand(1.0f);  // Hard right turn (assuming 1.0 is right)
        if (parkingStepCounter > 100)
        { // Placeholder condition
            parkingState.store(ParkingState::TURNING_IN);
            parkingStepCounter = 0;
            std::cout << "VehicleController: Parking - Turning wheels in." << std::endl;
        }
        break;

    case ParkingState::TURNING_IN:
        // 3. Turn wheels hard left (or right) to align inside the spot
        sendMotorCommand(-0.3f); // Continue slow reverse
        sendServoCommand(-1.0f); // Hard left turn
        if (parkingStepCounter > 50)
        { // Placeholder condition
            parkingState.store(ParkingState::REVERSING_IN_FINAL);
            parkingStepCounter = 0;
            std::cout << "VehicleController: Parking - Final reverse." << std::endl;
        }
        break;

    case ParkingState::REVERSING_IN_FINAL:
        // 4. Continue reversing to pull fully into the spot
        sendMotorCommand(-0.3f); // Slow reverse
        sendServoCommand(-1.0f); // Keep left turn
        if (parkingStepCounter > 80)
        { // Placeholder condition
            parkingState.store(ParkingState::TURNING_STRAIGHT);
            parkingStepCounter = 0;
            std::cout << "VehicleController: Parking - Straightening wheels." << std::endl;
        }
        break;

    case ParkingState::TURNING_STRAIGHT:
        // 5. Straighten the wheels
        sendMotorCommand(0.0f); // Stop
        sendServoCommand(0.0f); // Center steering
        // Small delay to let steering settle?
        if (parkingStepCounter > 20)
        { // Placeholder condition
            parkingState.store(ParkingState::PARKING_COMPLETE);
            parkingStepCounter = 0;
            std::cout << "VehicleController: Parking - Sequence complete." << std::endl;
        }
        break;

    case ParkingState::PARKING_COMPLETE:
        // Parking finished successfully
        parkingActive.store(false);
        maneuverInProgress.store(false);
        parkingStepCounter = 0;
        // Ensure stopped
        sendMotorCommand(0.0f);
        sendServoCommand(0.0f);
        std::cout << "VehicleController: Parking completed successfully." << std::endl;
        break;

    case ParkingState::PARKING_FAILED:
        // Parking failed, stop and exit sequence
        parkingActive.store(false);
        maneuverInProgress.store(false);
        parkingStepCounter = 0;
        sendMotorCommand(0.0f);
        sendServoCommand(0.0f);
        std::cout << "VehicleController: Parking failed." << std::endl;
        break;

    default:
        // Should not happen
        parkingActive.store(false);
        maneuverInProgress.store(false);
        sendMotorCommand(0.0f);
        sendServoCommand(0.0f);
        std::cerr << "VehicleController: Unexpected parking state." << std::endl;
        break;
    }
}

bool VehicleController::isManeuverActive() const
{
    return maneuverInProgress.load();
}
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

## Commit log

2025-08-13 first commit with body frame stl
2025-08-19 chassish design and sample testing code for pi working
    [AxisHolder.stl, AxisRingsx6.stl, Axles.stl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]
2025-08-23 Add Pi Zero 2W vision to serial controller script
    - Implemented a Python script for controlling a Pi Zero 2W with vision capabilities.
    - Integrated OpenCV for camera input and color detection (red and green).
    - Established serial communication with an Arduino for command transmission.
    - Added threading for continuous serial reading without blocking the main loop.
    - Implemented a simple steering control based on lane detection and color signals.
    - Included command sending at controlled intervals to manage vehicle speed and steering angle.
    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
2025-08-23 Refactor MPU6050 initialization and improve sensor reading functions
2025-08-24 Add power source configuration and connection details for the system
    - Created a new CSV file detailing the power source components and their connections.
    - Included specifications for Battery Pack, Buck Converter, Raspberry Pi, Arduino Nano, sensors, and motors.
    - Provided notes on power requirements and precautions for each component.
    [data_connection.csv, power_source.csv]
2025-08-25 Refactor pi_main.py for improved error handling, camera initialization, and control logic. Streamlined serial communication and enhanced logging for better debugging. Adjusted frame processing and ad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
2025-08-26 Enhance camera initialization with detailed logging and improved error handling. Updated to use V4L2 backend and report actual camera settings.
2025-08-26 Modify start button handling for single press detection and debounce logic
2025-08-26 Refactor code structure for improved readability and maintainability
    [Super Stantia-Hango.stl]
2025-08-27 Implement Arduino Nano and Raspberry Pi communication for autonomous vehicle control
    - Added Arduino Nano code for sensor integration, motor control, and servo steering.
    - Implemented serial communication to send and receive commands between Raspberry Pi and Arduino.
    - Developed Raspberry Pi main control logic for processing camera frames, calculating control commands, and managing vehicle states (driving, parking, stopped).
    - Integrated logging for debugging and monitoring system performance.
    - Established sensor data parsing and handling for IR sensors, ultrasonic sensors, and IMU data.
    - Included error handling and reconnection logic for serial communication.
2025-08-27 Refactor nano_code.ino for single motor control and MPU6050 integration. Improved button handling, sensor reading, and command processing. Enhanced logging for initialization and calibration.
2025-08-27 Refactor pi_main.py for improved structure and readability. Consolidated configuration parameters, enhanced serial and camera initialization, and streamlined sensor data parsing. Updated frame proces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
2025-08-27 Refactor test_serial.ino for improved sensor reading and command processing. Implemented non-blocking sensor reads, optimized data transmission, and enhanced command parsing efficiency.
2025-08-27 Refactor pi_main.py for improved structure and functionality. Enhanced camera and serial communication setup, optimized sensor data handling, and streamlined control logic for lap counting and parkin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
2025-08-28 Add serial communication and control logic for Raspberry Pi and Arduino Nano
    - Implemented a Python script for Raspberry Pi to communicate with Arduino Nano via serial.
    - Established a high-speed binary protocol for sensor data exchange.
    - Integrated camera functionality for vision processing and lane detection.
    - Developed control logic for driving, obeying traffic signs, and parking maneuvers.
    - Added logging for better debugging and monitoring of the system.
    - Created a test script for serial communication with the Arduino.
    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
2025-08-28 Implement WRO 2025 Car Controller for Raspberry Pi
    - Initialize serial communication with Arduino Nano for sensor data.
    - Set up camera for lane detection and sign recognition.
    - Implement state machine for driving laps, obeying signs, and parking maneuvers.
    - Add functions for processing sensor data, detecting track features, and calculating control commands.
    - Integrate logging for monitoring system behavior and debugging.
    - Handle graceful shutdown on interrupt signal.
2025-08-28 Add gyro calibration and improve control command calculations in pi_main.py
2025-08-30 Add README and initial Arduino Nano code for WRO 2025 project
2025-08-30 Refactor repository structure and update .gitignore
    - Enhanced .gitignore to include additional files and directories for better version control.
    - Updated README.md to reflect the current repository structure, clarifying the purpose of various directories and files.
    - Improved documentation for the nano_brain.ino file, including better organization of code and comments for clarity.
    - Added performance videos and known issues sections to README.md for comprehensive project documentation.
2025-09-20 Add core components for vehicle navigation and vision processing
    - Implement LapCounter class to track laps completed by the vehicle.
    - Define SensorData structure for sensor data received from the Nano.
    - Create CameraInterface for camera capture using OpenCV, including initialization and frame capture logic.
    - Develop ImageProcessor for processing frames and detecting traffic signs and track edges.
    - Introduce FrameBuffer for thread-safe storage of the latest frame.
    - Establish PositionalMemory for storing and comparing positional data for navigation.
    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
2025-09-22 Fix PathPlanner errors related to MissionState::ChallengeType declaration
    - Added missing declaration for MissionState::ChallengeType in path_planner.cpp.
    - Resolved compilation errors by ensuring proper inclusion of mission_state.h.
    - Addressed warnings for unused variables and parameters in path_planner.cpp.
    - Updated CMakeLists.txt to ensure proper build configuration.
    [main.cpp, path_planner.cpp, serial_handler.cpp]
2025-09-23 Add vision processing module and sensor connection diagrams
    - Created vision module with VisionSnapshot, DetectedSign, and DetectedEdgeLine classes for enhanced image processing.
    - Implemented methods for sign detection, edge tracking, and conflict resolution in navigation.
    - Added CSV files for sensor connections including ultrasonic sensors, motor driver (L298N), servo, and MPU6050.
    - Developed a test program for camera stream access and JPEG decoding using OpenCV.
    - Included an I2C scanner sketch for detecting connected IMU devices.
    [table-712bce07-e86a-4203-93f9-ff163939c866-12.csv, table-712bce07-e86a-4203-93f9-ff163939c866-17.csv, table-712bce07-e86a-4203-93f9-ff163939c866-22.csv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]
2025-09-25 Refactor code structure and remove redundant changes
    [pi_configuration.txt]
2025-09-25 Enhance vehicle control and camera interface functionality
    - Updated VehicleController to use camelCase for serial handler method names for consistency.
    - Refactored CameraInterface to improve frame capture logic and error handling, ensuring better performance on Raspberry Pi Zero 2 W.
    - Adjusted vehicle configuration to allow environment variable overrides for camera settings.
    - Removed unused init file in vision module to streamline the codebase.
    [main.py, vehicle_config.py, vehicle_controller.py]
2025-11-18 wro pic,national,delete image,camera pipeline,interface,expanse
2025-11-30 Add ESP32 LED blink example code
